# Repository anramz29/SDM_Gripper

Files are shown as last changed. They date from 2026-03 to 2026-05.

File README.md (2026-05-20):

# 1-DOF Underactuated Robotic Hand with Adaptive Grasping via Torsional Springs

**Adrian** — Northeastern University, EECE5554

A four-finger underactuated robotic gripper inspired by the SDM Hand (Dollar & Howe), designed and simulated in SolidWorks. The gripper achieves adaptive grasping across varied object geometries using a single actuator per finger and passive torsional springs.

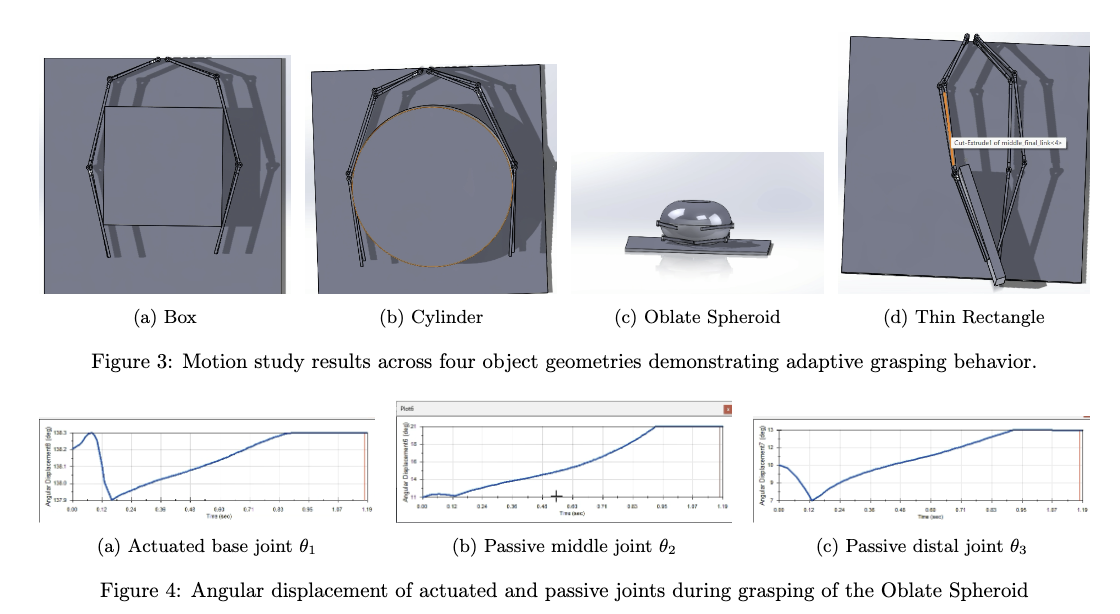
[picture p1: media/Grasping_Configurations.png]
Grasping Configurations


## How to Run

**Requirements:** SolidWorks with the Motion Analysis add-in enabled.

1. Open `cad/assemblies/final_assem.SLDASM` in SolidWorks. If prompted to locate missing references, point each part to the corresponding `.SLDPRT` file in `cad/parts/`.
2. In the bottom panel, select the **Motion Study** tab.
3. Click **Calculate** (or **Play**) to run the simulation.
4. To test a different object geometry, suppress the current object body in the assembly tree and unsuppress the desired one, then recalculate.

## Overview

Fully actuated robotic hands offer dexterity but are mechanically complex. Simple grippers lack versatility. This design occupies the middle ground: a **1-DOF-per-finger underactuated hand** that uses torsional springs at passive joints to conform to object geometry without additional actuation.

Each finger has **3 DOF** (proximal, middle, distal) but only **1 actuated DOF** — a tendon force applied at the distal link tip directed radially inward. The remaining 2 DOF per finger are governed by torsional springs, giving the full 4-finger hand **12 total DOF with only 4 actuated**.

## Mechanism Design

### Finger Structure

Each finger is a planar serial chain of three rigid links connected by revolute joints:

| Link | Length (mm) | Joint Angle | Type |
|---|---|---|---|
| Proximal | 100 | θ₁ ∈ [0°, −47°] | Actuated |
| Middle | 180 | θ₂ = 30° | Passive |
| Distal | 194 | θ₃ = 30° | Passive |

The four fingers are arranged symmetrically around a central palm structure.

### Spring Configuration

Torsional springs at each revolute joint bias the fingers toward closure:

- **Proximal & middle joints:** k = 18 N·mm/deg
- **Distal joint:** k = 5 N·mm/deg (greater fingertip compliance)
- **Damping:** C = 15 N·mm/(deg/s), linear type

Springs are wound inward (counter-clockwise on left fingers, clockwise on right), maintaining a non-zero passive joint angle at rest and keeping fingers away from kinematic singularities.

## Mobility & DOF Analysis

Using the planar Grübler formula for a single finger (n = 4 links, j₁ = 3 revolute joints):

```
M_finger = 3(4 − 1) − 2(3) = 3
M_hand   = 4 × 3 = 12  (4 actuated, 8 passive)
```

## Forward Kinematics

End-effector position for a single finger (passive joints fixed at spring-free angle):

```
x = l₁cos(θ₁) + l₂cos(θ₁+θ₂) + l₃cos(θ₁+θ₂+θ₃)
y = l₁sin(θ₁) + l₂sin(θ₁+θ₂) + l₃sin(θ₁+θ₂+θ₃)
```

Sweeping θ₁ across its full ~47° range traces the end-effector workspace. In practice, passive joints rotate freely in response to contact, extending the effective reachable configurations.

## SolidWorks Motion Study

### Simulation Setup

- **Actuation:** 1 N force applied at the distal link tip, directed radially inward (force vector rotates with the finger)
- **Material:** Rubber (dry) on arms and objects to simulate soft finger pads and increase friction
- **Objects tested:** Box, cylinder, oblate spheroid, thin rectangle

### Results

| Object | Outcome |
|---|---|
| Box | Stable, uniform contact distribution |
| Cylinder | Best demonstrated adaptive wrapping behavior |
| Oblate Spheroid | Each finger found stable configuration despite curved profile |
| Thin Rectangle | Least uniform — inconsistent closure rate caused object to shift before stabilizing |

Angular displacement plots confirm that the actuated base joint θ₁ shows a transient spike (force overcoming static spring resistance), while passive joints θ₂ and θ₃ demonstrate smooth independent rotation — validating that the torsional springs successfully transmit closure through the kinematic chain.

## CAD Files

All parts modeled in SolidWorks (`.SLDPRT`), assembled in `cad/assemblies/final_assem.SLDASM`.

**Assemblies** (`cad/assemblies/`)

| File | Description |
|---|---|
| `final_assem.SLDASM` | Main assembly |
| `final_assem_backup.SLDASM` | Backup assembly |

**Parts** (`cad/parts/`)

| File | Description |
|---|---|
| `final_base.SLDPRT` | Palm/base structure |
| `distal_link_final.SLDPRT` | Distal phalanx |
| `middle_final_link.SLDPRT` | Middle phalanx |
| `pin.SLDPRT` | Revolute joint pin |
| `sphere.SLDPRT` | Spherical test object |
| `final_bottle.SLDPRT` | Bottle-shaped passive element |
| `final box.SLDPRT` | Box test object |

## Media

Simulation videos are in the `media/` folder:

| File | Description |
|---|---|
| `final_assem.mp4` | Primary assembly demonstration |
| `final_assem_sq.mp4` | Box/square object grasping |
| `final_assem_bigger_cir.mp4` | Larger cylinder grasping |
| `final_assem_oblate.mp4` | Oblate spheroid grasping |
| `sphere_vid.mp4` | Spherical object grasping |

## References

1. A. M. Dollar and R. D. Howe, "The highly adaptive SDM hand: Design and performance evaluation," *IJRR*, vol. 29, no. 5, pp. 585–597, 2010.
2. M. Ciocarlie and P. Allen, "Hand posture subspaces for dexterous robotic grasping," *IJRR*, vol. 28, no. 7, pp. 851–867, 2009.
3. C. Gosselin, F. Pelletier, and T. Laliberte, "An anthropomorphic underactuated robotic hand with 15 dofs and a single actuator," pp. 749–754, 2008.
4. R. R. Ma and A. M. Dollar, "An underactuated hand for efficient finger-gaiting-based dexterous manipulation," *IEEE ROBIO*, 2014, pp. 2214–2219.

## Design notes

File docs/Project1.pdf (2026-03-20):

# Design and Analysis of a 1-DOF Underactuated Robotic Hand with Adaptive Grasping via Torsional Springs

Adrian

Northeastern University — EECE5554

March 20, 2026

link to one drive video (https://northeastern-my.sharepoint.com/:f:/r/personal/ramirez_adr_northeastern_edu/Documents/Project_1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)

## 1 Introduction

Robotic grasping remains a fundamental bottleneck in manipulation, on one side fully actuated hands offer dexterity but are complex, on the other simpler grippers lack versatility. Underactuated hands offer a compelling tradeoff being able to achieve adaptive grasping across objects using minimal actuators. This works designs a four-finger underactuated robotic hand inspired by the SDM Hand [1], using torsional springs to achieve this across four different object geometries.

## 2 Literature Survey

Underactuated robotic hands have been studied extensively as a middle ground between simple grippers and fully actuated dexterous hands.

Table 1: Literature Survey: Underactuated Robotic Hand Designs

Author(s) | Design | Act./Total DOF | Underactuation Method | Relevance
Dollar & Howe [1] | SDM Hand | 1/4 | Compliant joints | Primary inspiration
Ciocarlie & Allen [2] | Columbia Hand | 1/8 | Tendon + spring | Tendon-driven alternative
Gosselin et al. [3] | Linkage fingers | 1/3 | Rigid linkage | Analytical framework
This work | CAD model | 1/4 | Torsional springs + force | Simplified linkage implementation

This work implements a simplified version of the SDM approach using torsional springs in a rigid linkage model, validated through SolidWorks motion simulation.

## 3 Mechanism Description

### 3.1 Design Overview

The proposed mechanism is a four-finger underactuated robotic gripper, based on the original SDM Hand design of Dollar and Howe [1]. Each finger consists of three rigid links, proximal, middle, and distal, connected by revolute joints, with the proximal link attached to a central palm structure. The lengths of the three links are l1 = 100 mm, l2 = 180 mm, and l3 = 194 mm respectively. All revolute joint axes are parallel, constraining finger motion to a single plane. The four fingers are arranged symmetrically around the palm, with each finger forming an open kinematic chain from the palm to the distal link tip. The CAD model is seen in Figure 1a.
The gripper employs a 1-actuator-per-finger strategy to achieve underactuated behavior, with a single force applied at the distal link tip directed radially inward toward the central palm axis, simulating tendon actuation as seen in Figure 1a. The force was applied relative to the distal link component with a magnitude of F = 1 N, ensuring the force vector rotates with the finger during closure.

In addition to the force vector, torsional springs are placed at each of the three revolute joints to bias each finger toward a closed configuration. Each spring was defined with the upstream link as the base component and the downstream link as the axis direction reference, for the distal joint, the middle link serves as the base component as no further links exist beyond the end effector. Spring direction was set to curl each finger inward toward the palm, counter-clockwise on the left fingers and clockwise on the right fingers as seen in Figure 1b . Spring stiffness was set to k = 18 N·mm/deg for the proximal and middle joints, and k = 5 N·mm/deg for the distal joint to allow greater compliance at the fingertip. Damping was enabled on all springs with a linear damping type and a coefficient of C = 15 N·mm/(deg/s).

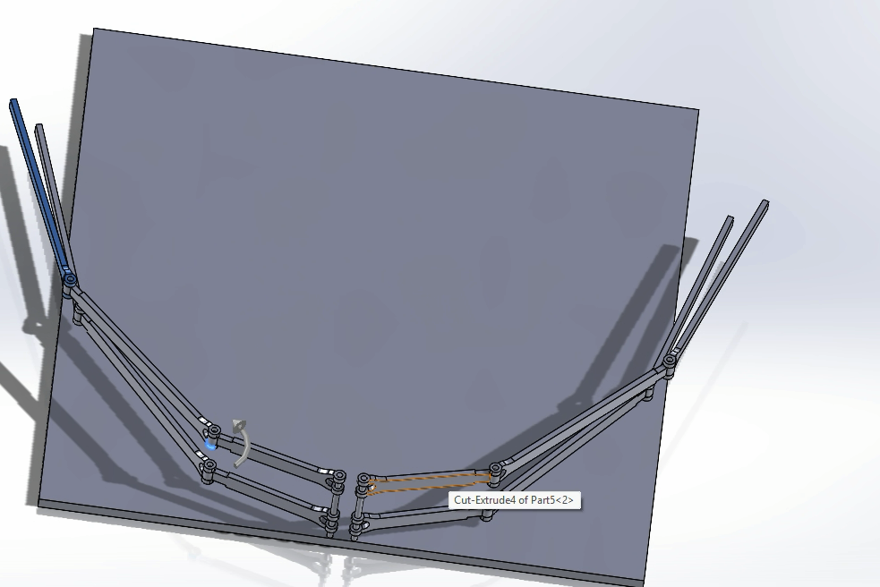
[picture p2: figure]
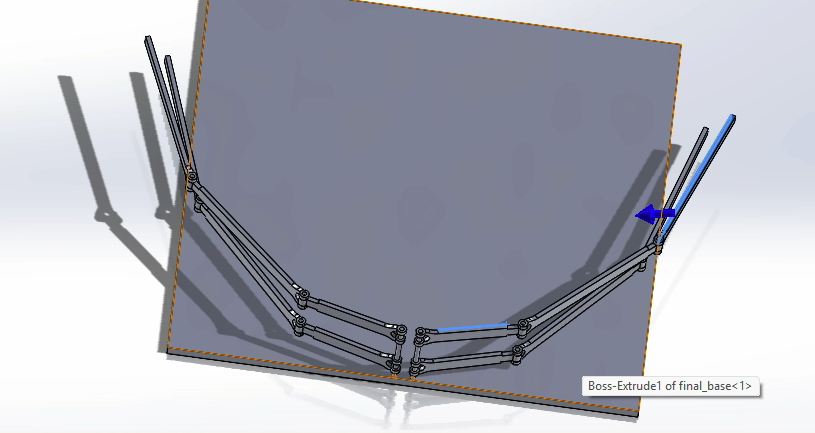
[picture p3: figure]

(a) Force Direction SDM | (b) Pinch grasp configuration.

Figure 1: Parameters and Structure of SDM Motion Study

## 4 Mobility and DOF Analysis

Each finger consists of three links (proximal, middle, and distal phalanx) connected by revolute joints, with the proximal link attached to the palm, giving n = 4 and j1 = 3 per finger. The mechanism does not contain closed kinematic chains, so j2 = 0. Although the model is in 3D space, it only uses revolute parallel joints, so the fingers only move in a single plane. Therefore the planar Gr¨ubler’s formula is appropriate.

Mf inger = 3(4 − 1) − 2(3) − 0 = 9 − 6 = 3 | (1)

The full hand consists of four such fingers, yielding a total DOF of:

Mhand = 4 × 3 = 12 | (2)

Of these 12 DOFs, only 4 are actuated, one tendon force applied per finger, leaving 8 passive DOFs. These passive DOFs are governed by the torsional springs at each joint, which bias the fingers toward closure and allow each finger to conform to object geometry without additional actuation. This 1-actuated/3-DOF per finger ratio is consistent with the SDM Hand design of Dollar and Howe [1].

## 5 Forward Kinematics

The forward kinematics of a single representative finger are computed geometrically, with analysis restricted to the actuated base joint θ1 as permitted for underactuated systems. Due to the symmetric design, all four fingers follow identical kinematic behavior, differing only in their base orientation relative to the palm.

### 5.1 Reference Frames and Parameters

The kinematic parameters for a single finger are summarized in Table 2. Each joint angle is measured relative to the previous link, with θ1 swept across its full actuated range. Meanwhile θ2 and θ3 are fixed at there spring free angle configurations/

Table 2: Kinematic Parameters for Single Finger

Link | Length (mm) | Joint Angle | Type
Proximal Middle Distal | 100 180 194 | θ1 ∈ [0, −47] θ2 = 30 θ3 = 30 | Actuated Passive Passive

The end effector position is calculated using the planar serial chain FK equations.

x = l1 cos θ1 + l2 cos(θ1 + θ2) + l3 cos(θ1 + θ2 + θ3) | (3)
y = l1 sin θ1 + l2 sin(θ1 + θ2) + l3 sin(θ1 + θ2 + θ3) | (4)

### 5.2 Workspace and Range of Motion

Sweeping θ1 around it’s full range of about 50 traces at the end-effector when testing the large box. For the purpose of this analysis, the passive joints θ2 and θ3 are held fixed in their spring free angle configuration 30. In practice these joints rotate freely (as seen in section 6) in response to object contact.

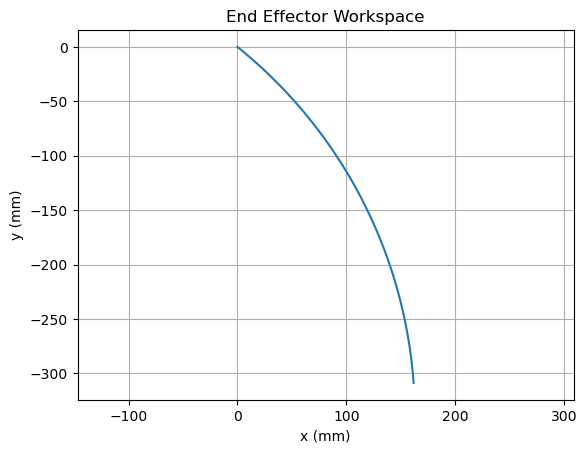
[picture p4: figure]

Figure 2: End effector workspace of a single representative finger, swept across the full actuated joint range of 47.

### 5.3 Singularity Analysis

A singularity occurs when all three links are fully extended and collinear, leading the Jacobian to lose rank and the end effector is unable to move perpendicular to the finger axis. This issue is completely avoided with torsional springs which maintain a non-zero passive joint angle at rest. This keeps the finger in a pre-grasp position away from possible singularities.

## 6 SolidWorks Motion Study

### 6.1 Simulation Setup

The spring and force configuration are already mentioned in section 3, for the other parameters included in the simulation. The Material of the box and arms was set to rubber (dry) allowing an increase in friction while mimicking the soft finger pads seen in [1]. The mechanism was tested on 5 different objects, a box, cylinder, oblate spheroid, thinner rectangle,

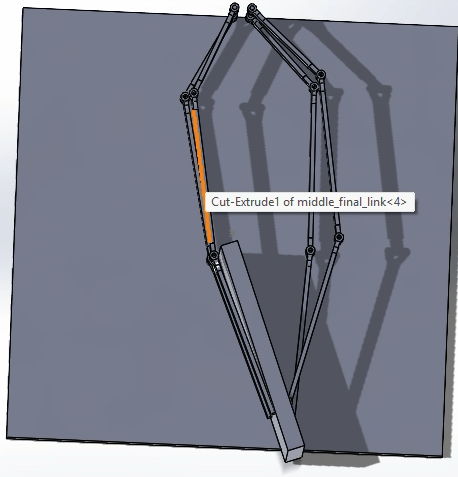
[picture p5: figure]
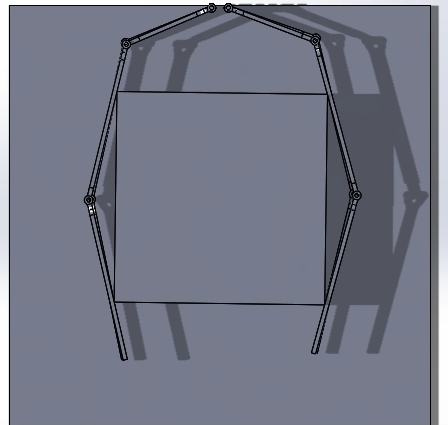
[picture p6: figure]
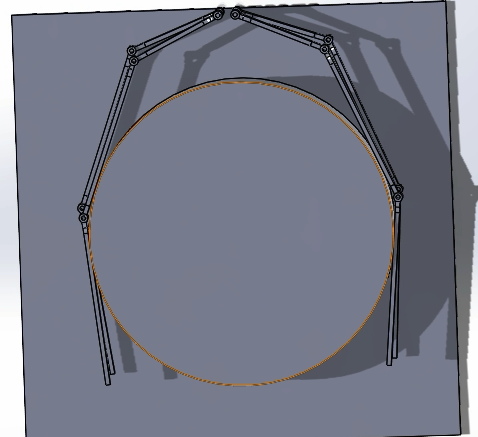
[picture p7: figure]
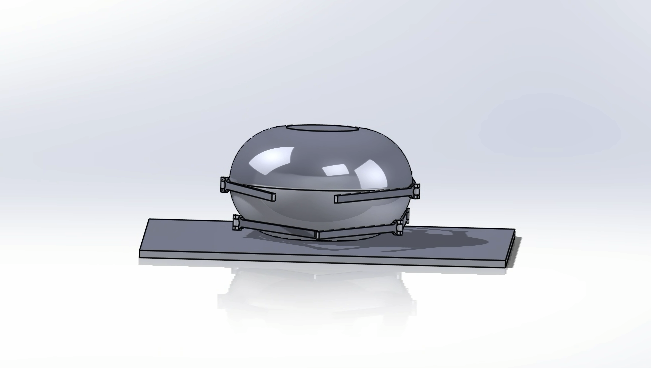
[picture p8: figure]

(a) Box | (b) Cylinder | (c) Oblate Spheroid | (d) Thin Rectangle

Figure 3: Motion study results across four object geometries demonstrating adaptive grasping behavior.

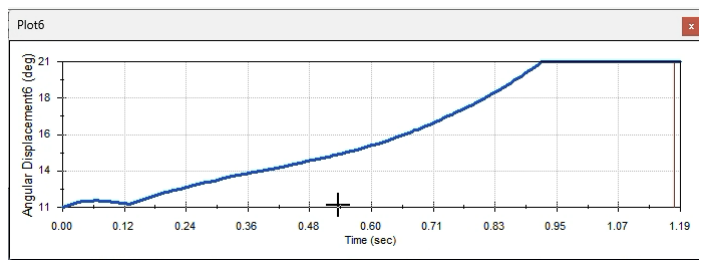
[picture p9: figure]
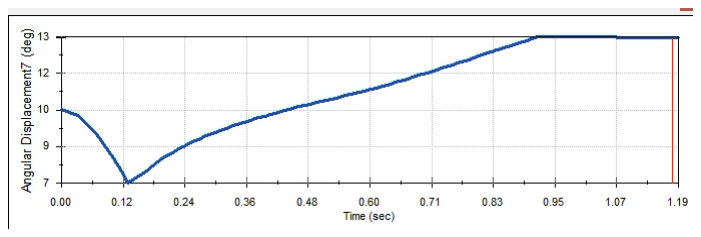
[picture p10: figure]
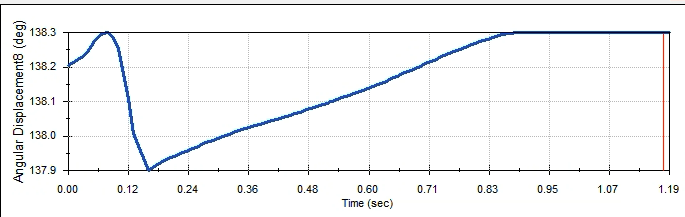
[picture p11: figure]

(a) Actuated base joint θ1 | (b) Passive middle joint θ2 | (c) Passive distal joint θ3

Figure 4: Angular displacement of actuated and passive joints during grasping of the Oblate Spheroid

### 6.2 Results

## 7 Discussion

The results demonstrate that the mechanism was able to achieve the adaptive grasping among varied object geometry. The box grasp produced stable and uniform contact distribution. The cylinder best demonstrated the adaptive wrapping behavior. The oblate spheroid presented a challenge with it’s curved profile but each arm was able to find a stable configuration. The thin rectangle produced the least uniform contact distribution as each finger had an inconsistent closure rate causing the object to shift until a stable albeit ugly final configuration, persistent and puzzling issue faced in SolidWorks.
The angular displacement plots tell us that the actuated base joint θ1 has a transient spike, typical of the force overcoming static spring resistance. The passive joints θ2 and θ3 demonstrate smooth independent rotation, confirming that the torsional springs successfully transmit closure motion through the kinematic chain.

## 8 Conclusion

To conclude, the proposed four-finger gripper was able to show adaptive grasping for different object geometries, using a simulated single actuator. This confirms the core principle that passive compliance can substitute for active control in specific situation. Possible extensions for this can include simulating Ma Dollar four-finger hand [4], which allows for finger-gaiting while retaining the passive adaptability.

## References

[1] A. M. Dollar and R. D. Howe, “The highly adaptive SDM hand: Design and performance evaluation,” The International Journal of Robotics Research, vol. 29, no. 5, pp. 585–597, 2010.
[2] M. Ciocarlie and P. Allen, “Hand posture subspaces for dexterous robotic grasping,” The International Journal of Robotics Research, vol. 28, no. 7, pp. 851–867, 2009.
[3] C. Gosselin, F. Pelletier, and T. Laliberte, “An anthropomorphic underactuated robotic hand with 15 dofs and a single actuator,” pp. 749–754, 2008.

[4] R. R. Ma and A. M. Dollar, “An underactuated hand for efficient finger-gaiting-based dexterous manipulation,” in Proceedings of the 2014 IEEE International Conference on Robotics and Biomimetics, Bali, Indonesia, 2014, pp. 2214–2219.

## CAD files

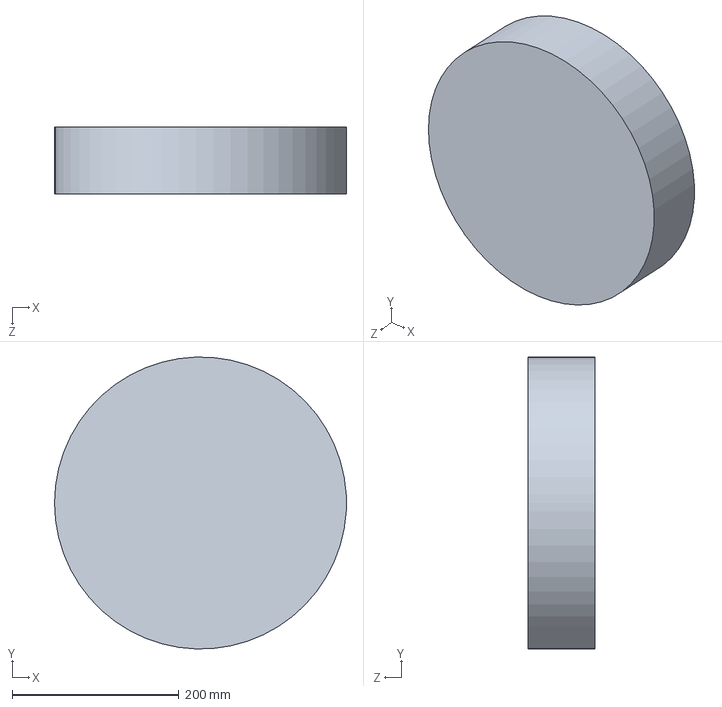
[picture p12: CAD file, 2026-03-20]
cad/parts/final_bottle.SLDPRT
350.0 x 349.8 x 80.0 mm

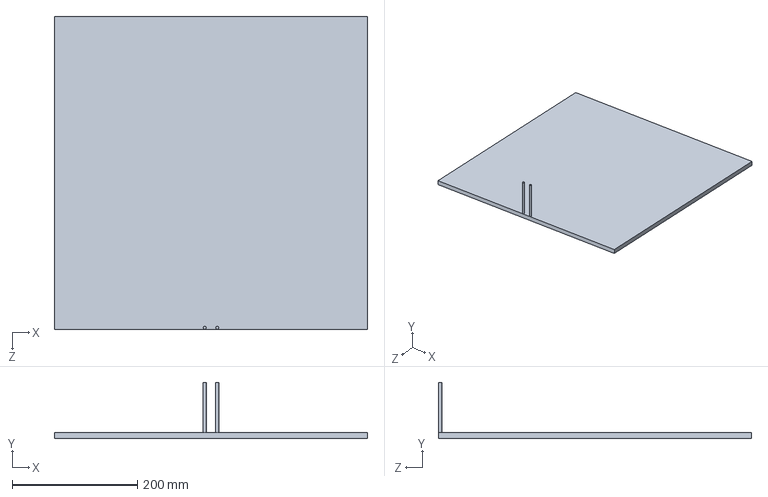
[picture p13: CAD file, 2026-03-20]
cad/parts/final_base.SLDPRT
500.0 x 90.0 x 500.0 mm

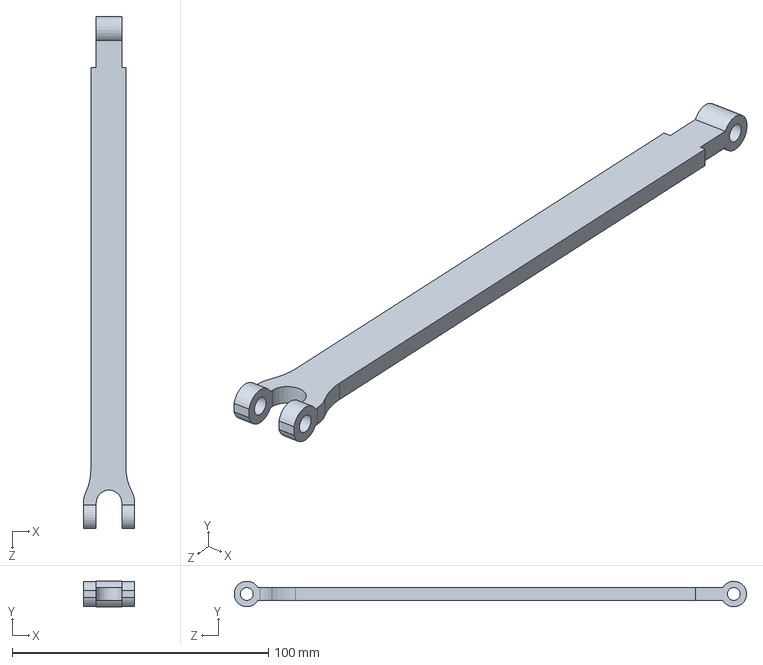
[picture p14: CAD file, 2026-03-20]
cad/parts/middle_final_link.SLDPRT
20.0 x 9.99 x 200.0 mm

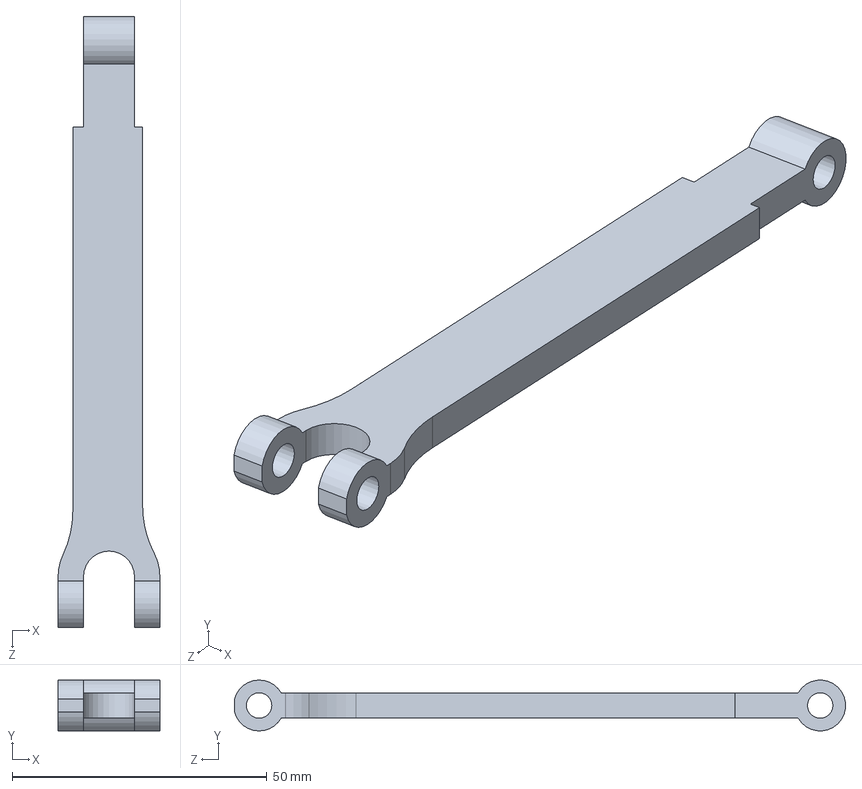
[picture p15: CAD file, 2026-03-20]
cad/parts/Part5.SLDPRT
20.0 x 10.00 x 120.0 mm

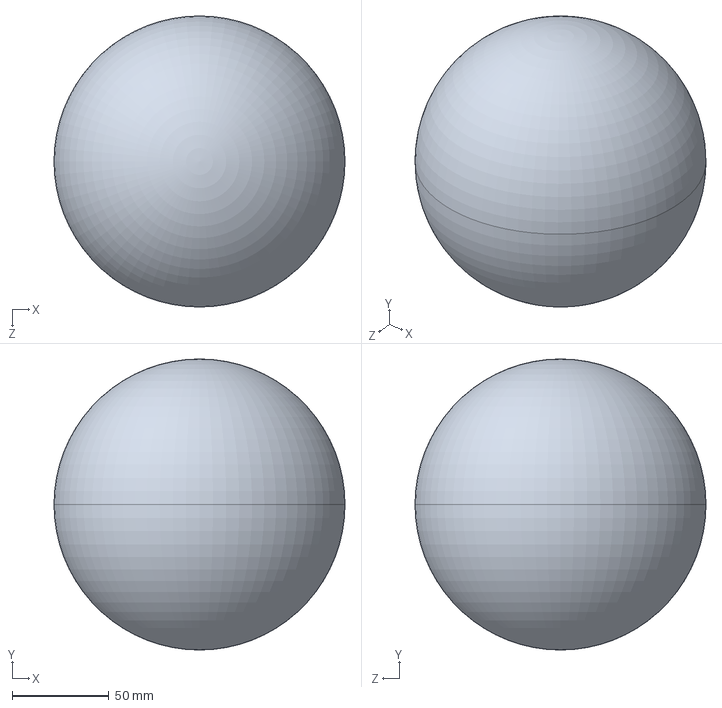
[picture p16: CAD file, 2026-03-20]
cad/parts/sphere.SLDPRT
150.0 x 150.0 x 150.0 mm

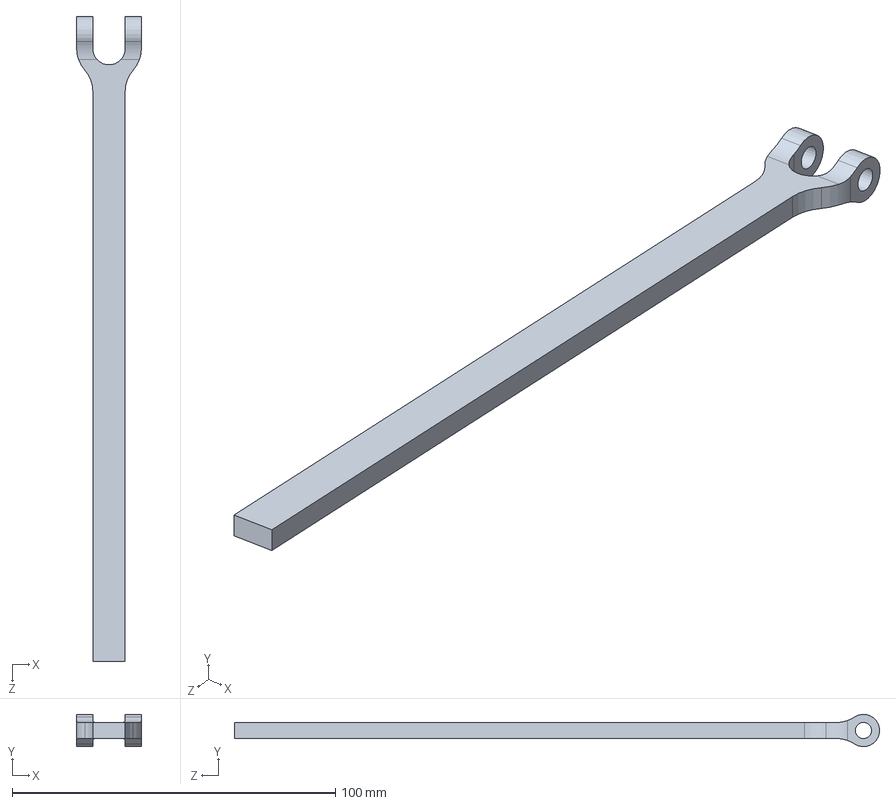
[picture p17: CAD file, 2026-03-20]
cad/parts/distal_link_final.SLDPRT
20.0 x 9.97 x 199.5 mm

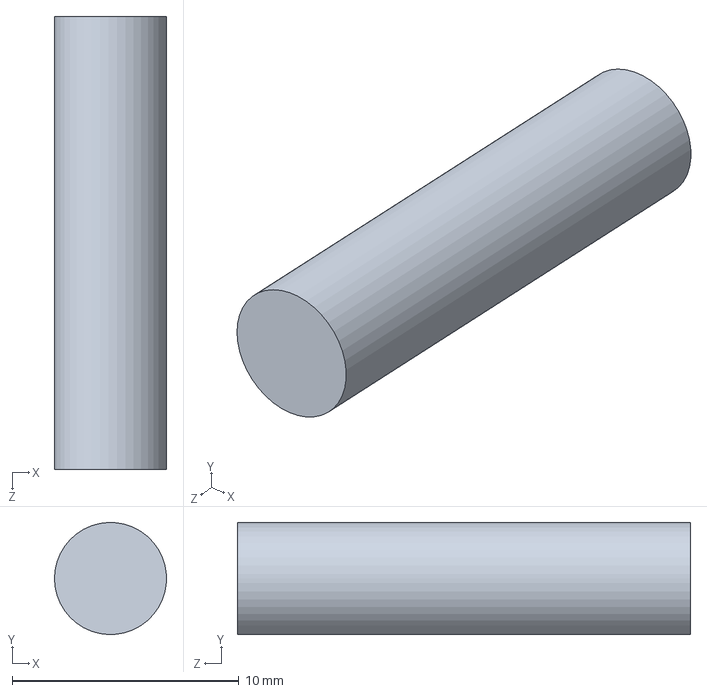
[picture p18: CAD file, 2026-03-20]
cad/parts/pin.SLDPRT
4.95 x 4.95 x 20.0 mm

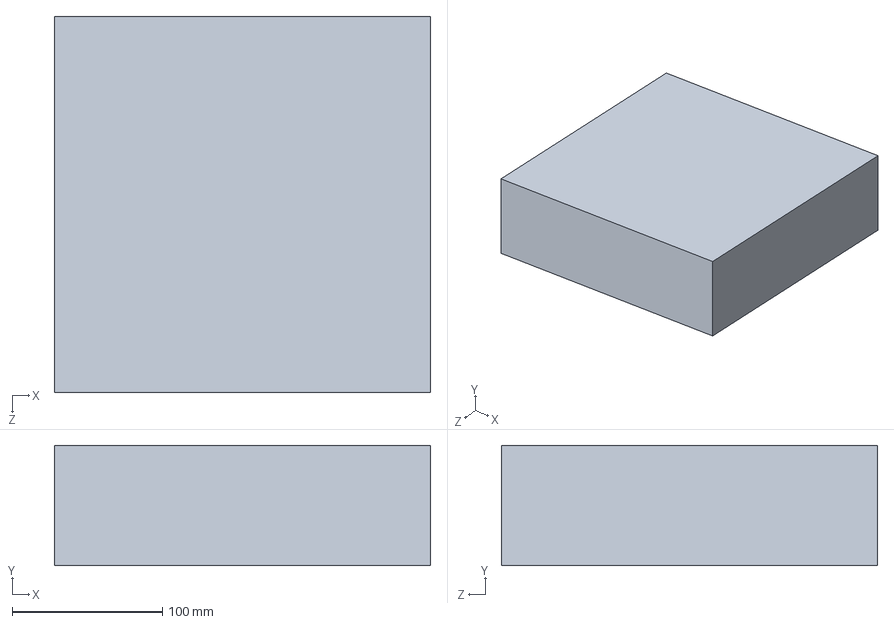
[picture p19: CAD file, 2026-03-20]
cad/parts/final box.SLDPRT
250.0 x 80.0 x 250.0 mm

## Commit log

2026-03-20 Add initial CAD files and README for 1-DOF underactuated robotic hand project
    [Part5.SLDPRT, distal_link_final.SLDPRT, final box.SLDPRT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]
2026-05-20 Add CAD files and update README with file paths; include .gitignore for SolidWorks
    [Part5.SLDPRT, distal_link_final.SLDPRT, final box.SLDPRT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]
